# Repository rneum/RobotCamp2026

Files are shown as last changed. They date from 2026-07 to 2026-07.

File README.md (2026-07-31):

PLEASE FILL OUT THE SURVEY HERE: https://utexas.qualtrics.com/jfe/form/SV_4Vpkfo9J5wA6hvg

This repository will hold the lab guides and code for the Robotics Summer Camp at The University of Texas at Austin for Summer 2026.
This camp will be based around the Longhorn Hapkit 1-DOF.
New files will be uploaded as the camp progresses so stay tuned!

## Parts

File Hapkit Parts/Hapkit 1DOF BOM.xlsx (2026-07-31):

Part | Qty per kit | Link
Motor | 1 | https://www.pololu.com/product/4860
Motor Driver L298N | 1 | https://www.amazon.com/dp/B0C5JCF5RS/ref=pe_386300_440135490_TE_simp_item
12V 2A Power Supply | 1 | https://www.amazon.com/dp/B0DFPNZ77T/ref=pe_386300_440135490_TE_simp_item?th=1
Barrel Jack adaptor | 1 | https://www.amazon.com/dp/B079RCNNCK/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
Arduino Uno | 1 | https://www.amazon.com/dp/B0B6VV7MS7?qty=65&sbo=RZvfv%2F%2FHxDF%2BO5021pAnSA%3D%3D
Jumper Wires M-M 10cm | 8 | https://www.amazon.com/dp/B0BRTL3BHR/ref=pe_386300_440135490_TE_simp_item?th=1
Jumper Wires M-M 20cm | 1 | https://www.amazon.com/gp/product/B0BRTJQZRD/ref=sw_img_1?th=1&qty=2
Jumper Wires F-M 20cm | 3 | https://www.amazon.com/California-JOS-Breadboard-Optional-Multicolored/dp/B0BRTHR2RL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
Ball bearing 608 | 2 | https://www.amazon.com/dp/B09PKD8QZZ/ref=pe_386300_440135490_TE_simp_item?th=1&qty=7
Philips #1 Screwdriver | 1 | https://www.amazon.com/Wiha-96110-Phillips-Screwdriver-Precision/dp/B0006OBFP4
4mm allen wrench | 1 | https://www.amazon.com/dp/B0D984S6SD/ref=pe_386300_440135490_TE_simp_item?th=1
Eyeglass screwdriver philips | 1 | https://www.amazon.com/TorSor-Eyeglass-Screwdriver-Keychain-Eyeglasses/dp/B0CM8SWMXC?s=hi&qty=6
Storage bin | 1 | https://www.amazon.com/dp/B01MR7L1VD?qty=6&sbo=RZvfv%2F%2FHxDF%2BO5021pAnSA%3D%3D
M6 shoulder bolts | 1 | https://www.mcmaster.com/92981A202/
M6x1 Nut | 1 | https://www.mcmaster.com/90591A151/
M3x0.5 10mm flat head screw | 9 | https://www.mcmaster.com/92010A120/
M3x0.5 Nut | 9 | https://www.mcmaster.com/91828A211/
M5x0.8 30mm socket screw | 1 | https://www.mcmaster.com/91290A194/
M5x0.8 nut | 1 | https://www.mcmaster.com/90591A260/
4-40 3/8" pan head screw | 2 | https://www.mcmaster.com/91735A104/
Compression fitting | 2 | https://www.mcmaster.com/3898T29/
Wire rope | 16" | https://www.mcmaster.com/8930T16-8930T543/
Wire rope (extra in case of breaks) |  | https://www.mcmaster.com/8930T16-8930T542/

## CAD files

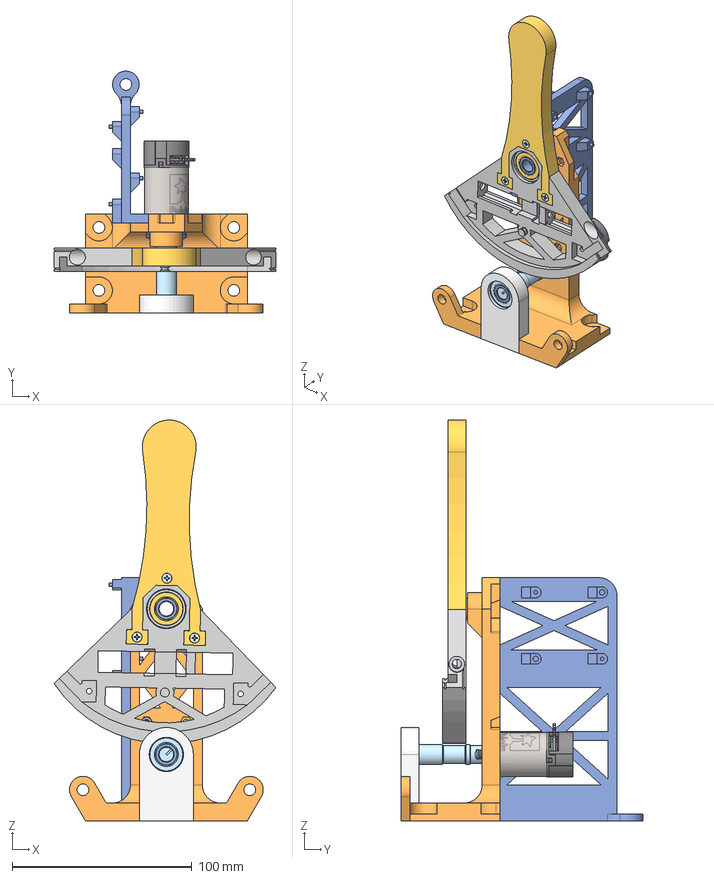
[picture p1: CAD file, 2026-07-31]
Hapkit Parts/1DOF STL/1-DOF Assembly.step
123.3 x 134.4 x 223.0 mm
PCB Mount
91828A211_Corrosion-Resistant 18-8 Stainless Steel Hex Nut x 5
25d-gearmotor-1-no-gearbox-encoder x 2
6153K71_Stainless Steel Ball Bearing x 32
91735A104_316 Stainless Steel Pan Head Phillips Screw x 4
Spacer x 2
Bearing Housing
Base for vert print
Motor Shaft
Handle
92010A120_Passivated 18-8 Stainless Steel Phillips Flat Head Screw x 5
Tensioner
Sector Pulley

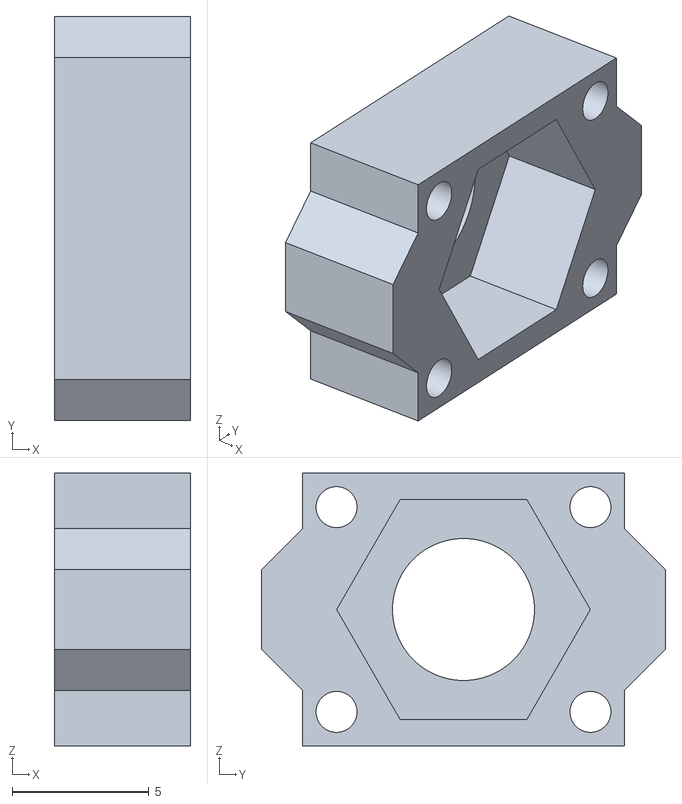
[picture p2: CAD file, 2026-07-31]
Hapkit Parts/1DOF STL/Tensioner.stl
5.00 x 14.8 x 10.0

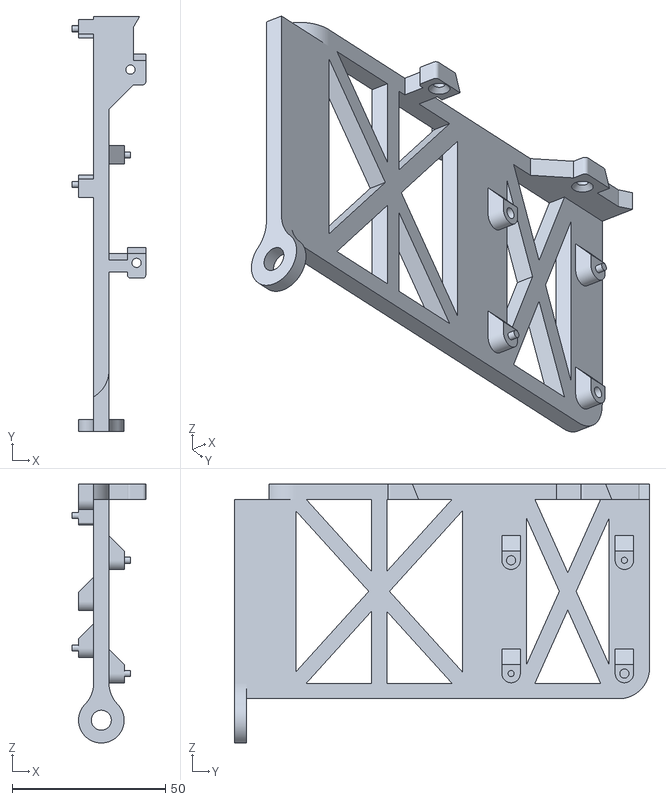
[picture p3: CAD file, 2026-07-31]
Hapkit Parts/1DOF STL/PCB Mount.stl
24.0 x 135.3 x 84.4

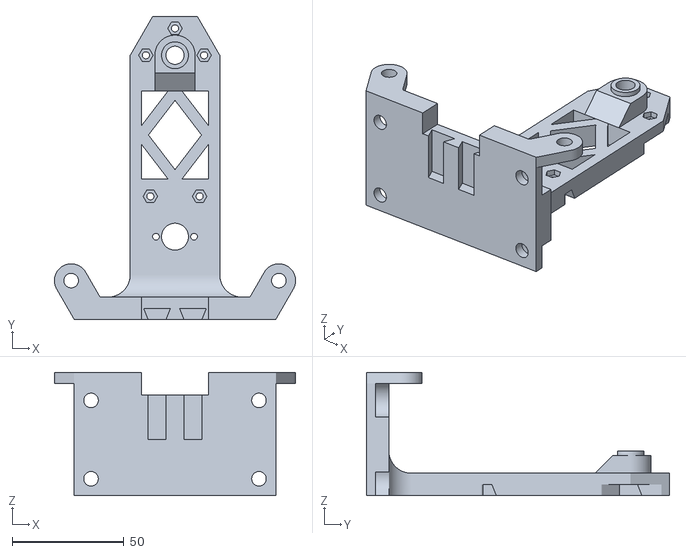
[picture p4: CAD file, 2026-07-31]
Hapkit Parts/1DOF STL/Base.stl
107.7 x 135.3 x 55.0

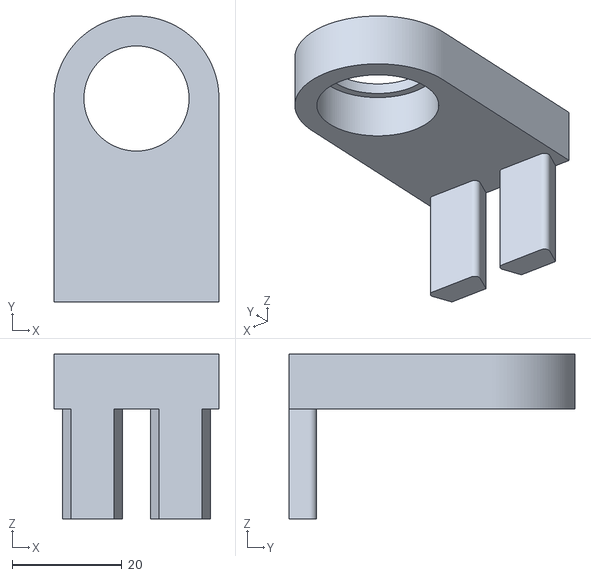
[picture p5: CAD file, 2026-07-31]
Hapkit Parts/1DOF STL/Bearing Housing.stl
30.0 x 52.0 x 30.0

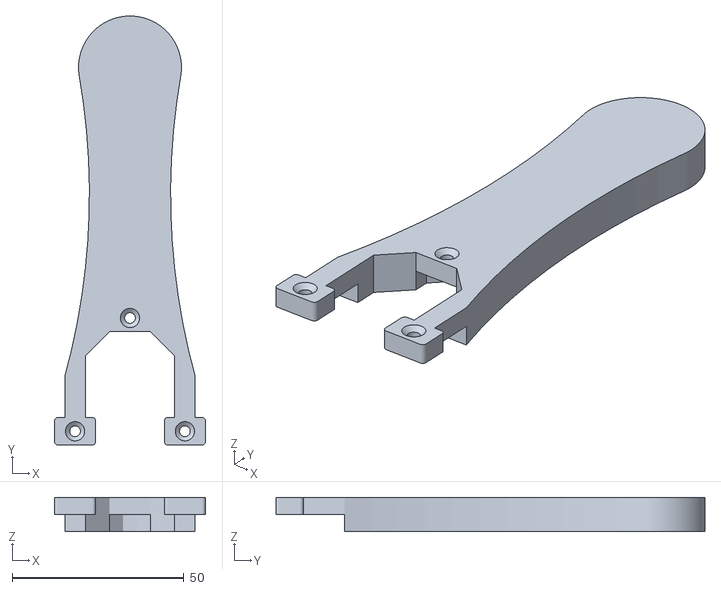
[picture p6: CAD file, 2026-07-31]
Hapkit Parts/1DOF STL/Handle.stl
44.0 x 125.0 x 10.0

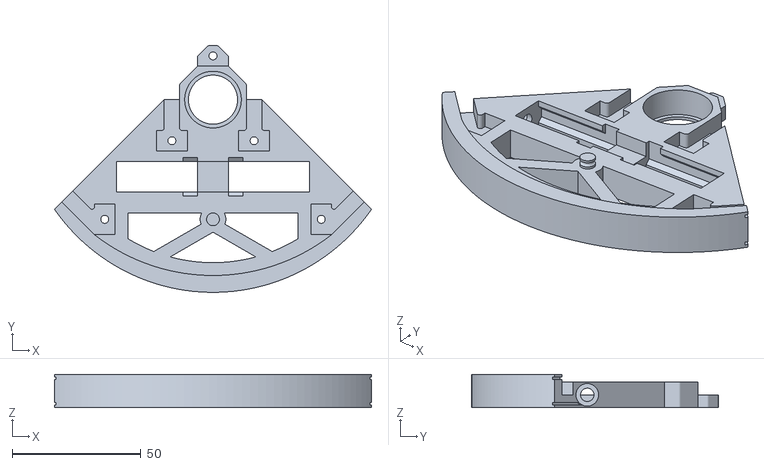
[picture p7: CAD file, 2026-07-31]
Hapkit Parts/1DOF STL/Sector.stl
123.4 x 96.0 x 13.0

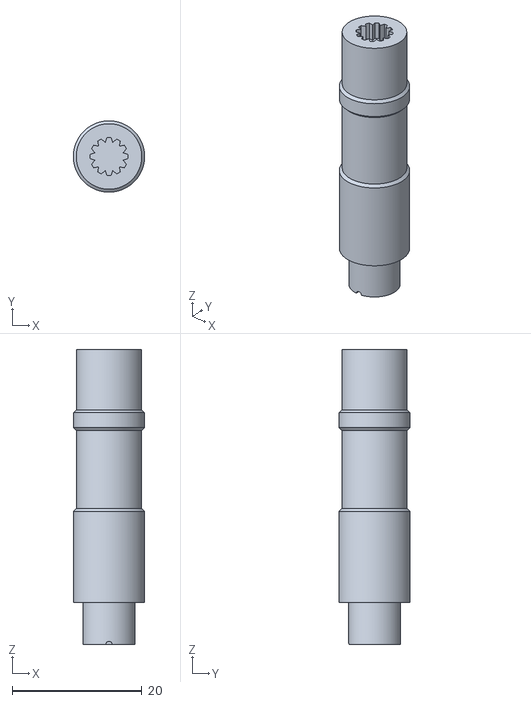
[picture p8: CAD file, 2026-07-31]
Hapkit Parts/1DOF STL/Motor Shaft.stl
11.0 x 11.0 x 45.5

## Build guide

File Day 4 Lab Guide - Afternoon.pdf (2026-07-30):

ROSS NEUMAN
Assistant Professor of Practice, The University of Texas at Austin

SUMMER 2026

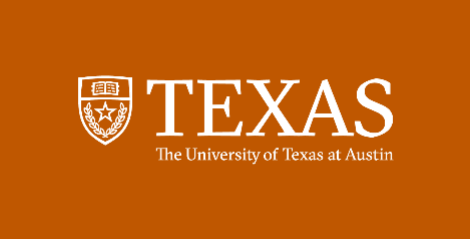
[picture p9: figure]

## LONGHORN HAPKIT

Lab guide #4 - afternoon

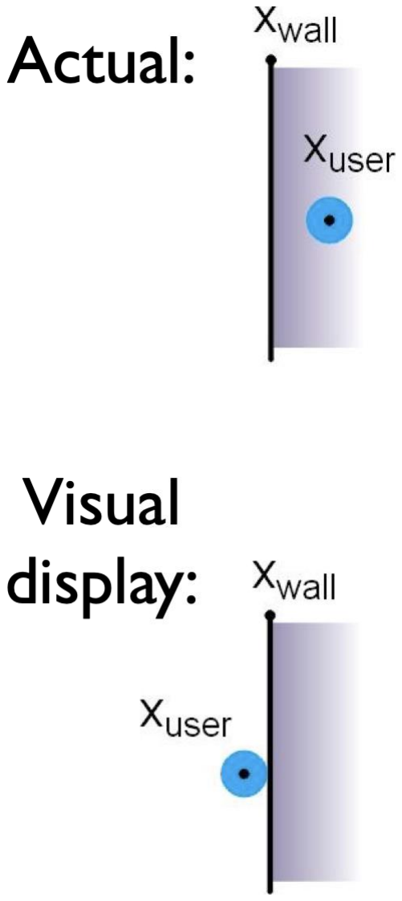
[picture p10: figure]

One more way to make a wall better: Visual Feedback of Stiffness
- trick: never show the point
passing into the surface, even if it is!
- psychophysical studies have shown that this makes the
surface appear stiffer to the user

Scripts are uploaded to show all environments we have discussed

- all_environments contains, well, all the environments we’ve talked about
- Let me know if you have questions about any of them

Making your PWM fast and silent

- all_environments_fast_PWM has the same environments, but with PWM at 20,000 Hz instead of 490

How did it become quiet?

- Default Arduino PWM frequency on pin 6 is 980Hz – This is basically a B5 for music people
– VERY audible
- Humans typically hear from about 20-20,000Hz
- ATmega328 chip (arduino’s brain) is capable of higher PWM – Need to talk directly with the timers
– Timer is a hardware counter that increments at a known rate derived from CPU clock
– CPU clock on arduino is 16MHz (16,000,000 cycles/second)

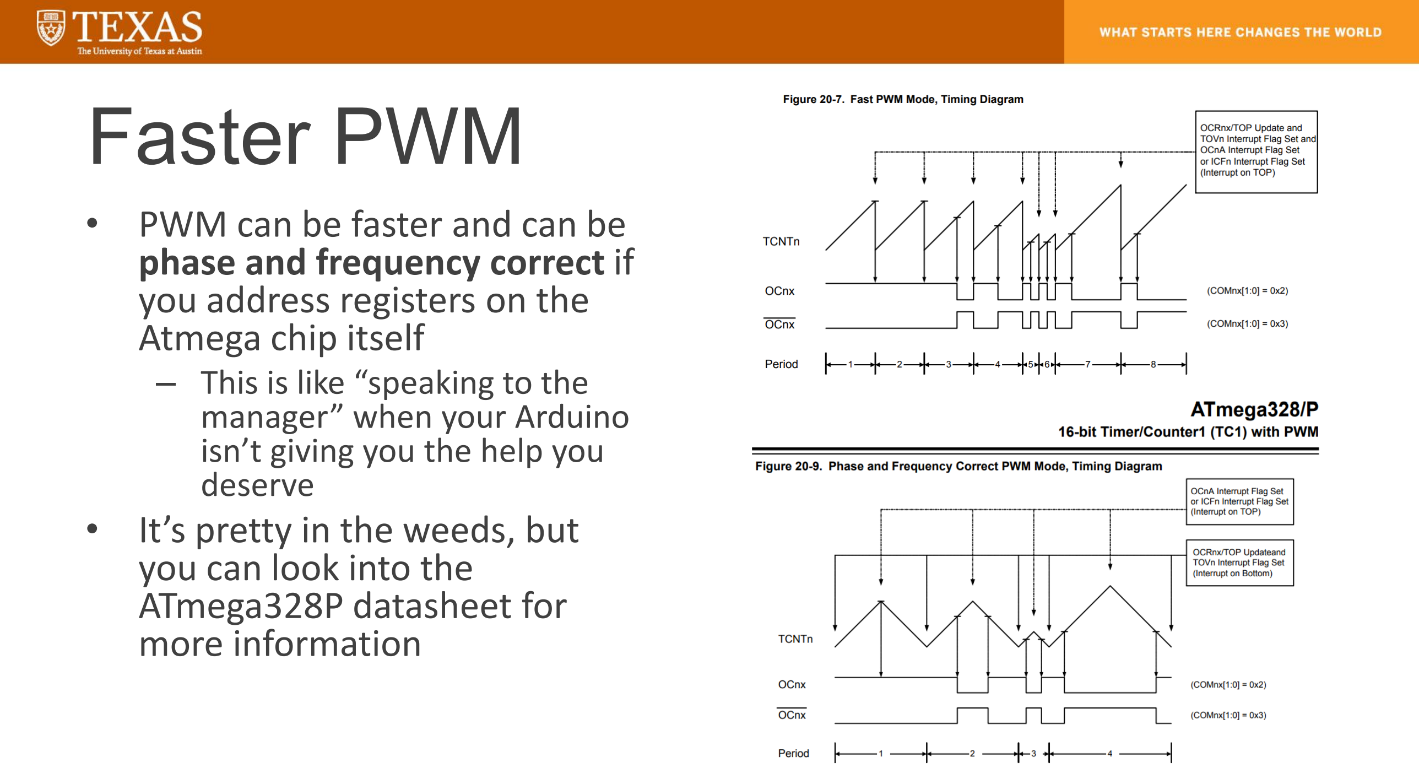
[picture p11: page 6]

Faster PWM

- PWM can be faster and can be phase and frequency correct if you address registers on the Atmega chip itself
– This is like “speaking to the manager” when your Arduino isn’t giving you the help you deserve
- It’s pretty in the weeds, but you can look into the
ATmega328P datasheet for
more information

Talking to the chip

- Rather than using built-in arduino commands, we are talking straight to the MCU onboard
- This mostly consists of setting registers

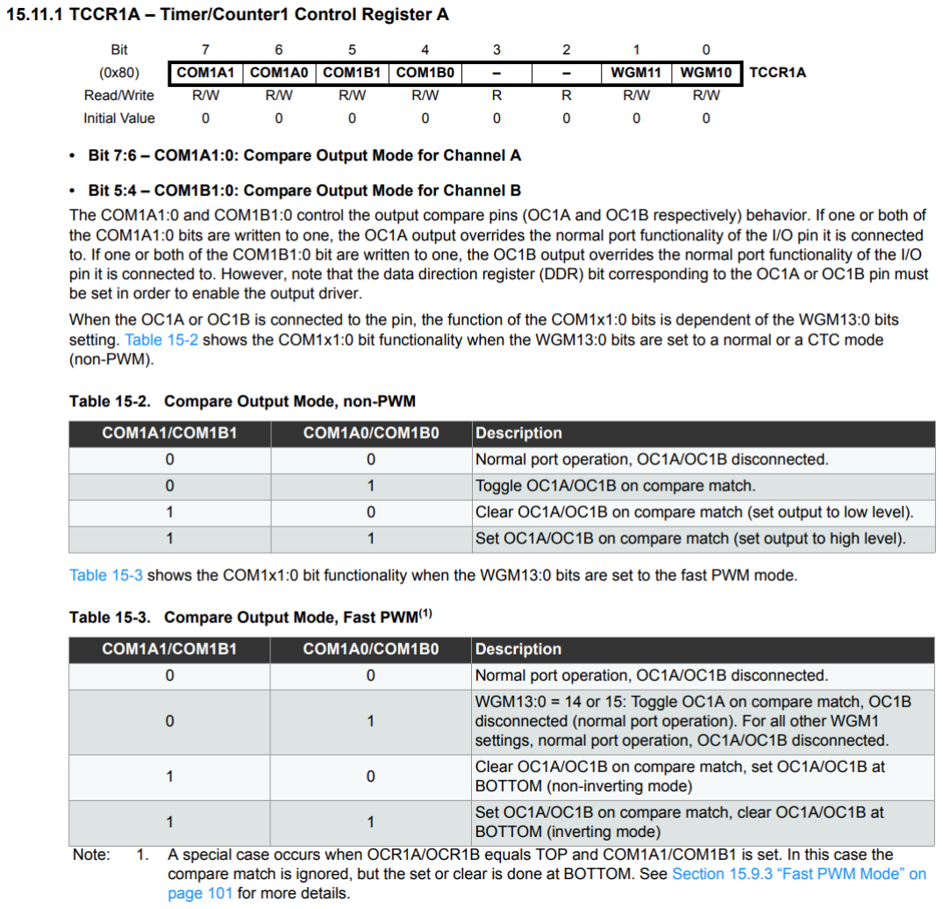
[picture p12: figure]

Registers

- Registers in this case are basically 8 bit numbers that tell the MCU different modes to operate in
- We are setting Timer/Counter1 Control Register A or TCCR1A to
- When we type
- TCCR1A = (1 << COM1A1);
- We are setting the value of TCCR1A to 10000000
- This sets non-inverting PWM

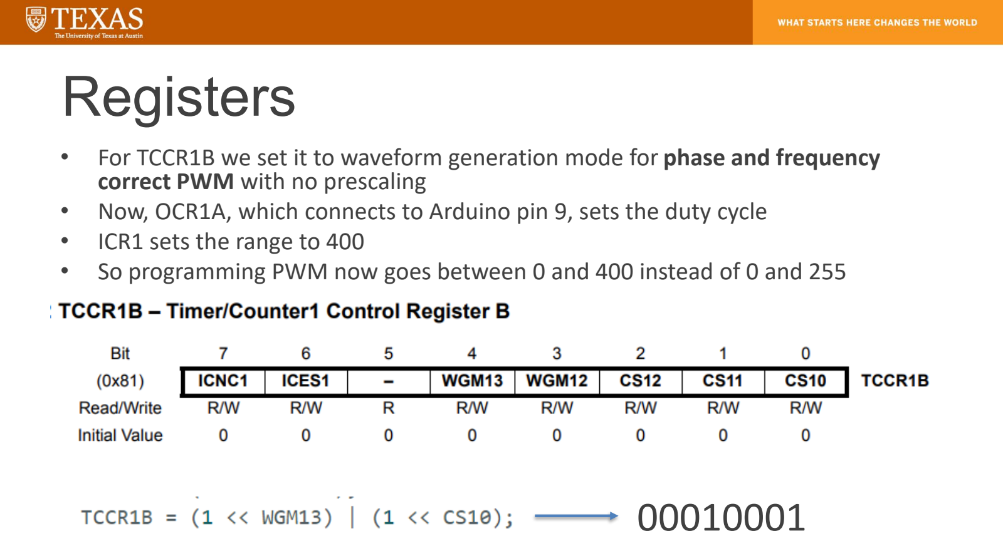
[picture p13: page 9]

Registers

- For TCCR1B we set it to waveform generation mode for phase and frequency correct PWM with no prescaling
- Now, OCR1A, which connects to Arduino pin 9, sets the duty cycle
- ICR1 sets the range to 400
- So programming PWM now goes between 0 and 400 instead of 0 and 255

00010001

Bot’n’Roll

- We have “botnroll one A” kits if you are tired of the hapkit
- Use in groups or pairs, not enough for everyone
- I have never used them, you’re on your own
- https://botnroll.com/onea_en/

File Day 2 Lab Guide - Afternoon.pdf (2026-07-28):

ROSS NEUMAN
Assistant Professor of Practice, The University of Texas at Austin

SUMMER 2026


## LONGHORN HAPKIT

Lab guide #2 - afternoon

After springs, bumps, and walls
- So far all of our commanded forces have been related to the position of the end-effector (handle)
- Sometimes we want to instead have them relate to the velocity of the handle

velocity =

position
time

How do we get the time?

- Currently our superloop simply runs as fast as it can
- This means we don’t have a good measure of how much time elapses between runs
- Solution: we make another loop that does run at a given time

Interrupt Service Routine (ISR)

- ISR uses a timer onboard the microcontroller and counts for a certain number of clock cycles
- Once it hits the number, it triggers the ISR to run immediately

How are we handling haptic loop now?

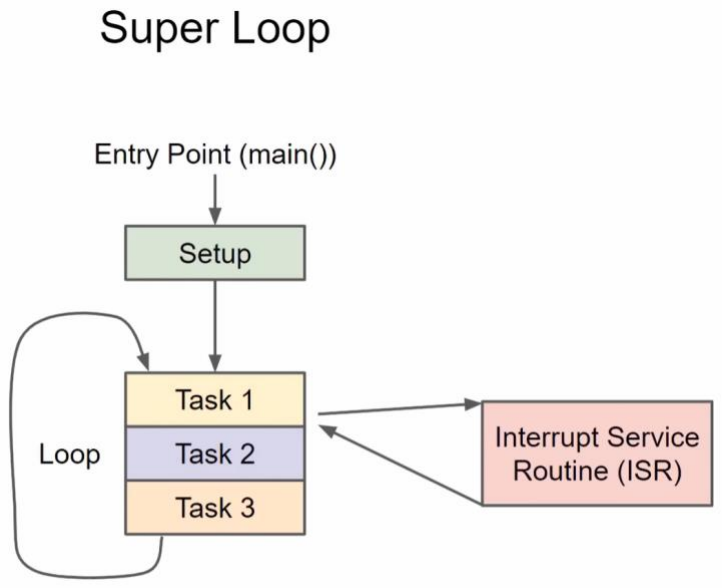
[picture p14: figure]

- Rather than running each loop
task sequentially, ISR initiates at
precise time intervals
– Processor finishes current instruction
– Jumps to ISR
- Only preempted by higher-priority interrupts like…?
- Encoder!
– This is fine because encoder is super fast

Haptic loop handling – ISR setup

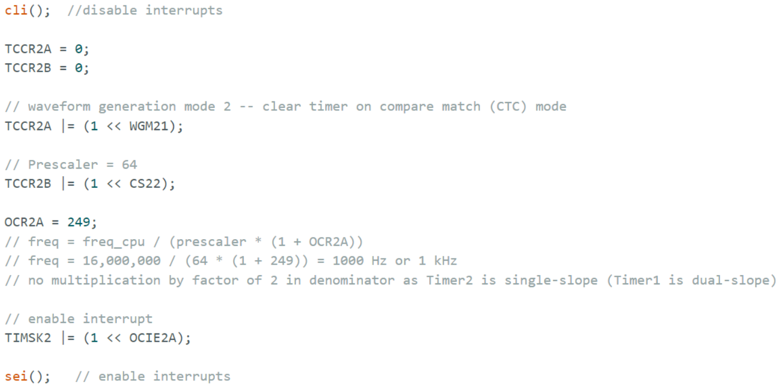
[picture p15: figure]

Haptic Loop Handling - ISR

- ISR is a separate loop from
the “superloop”
- Use this for computation of
quantities necessary to haptic rendering
- Do not use this for things like printing to serial monitor
– Serial prints are very slow
– This is what the regular loop() function can be used for now

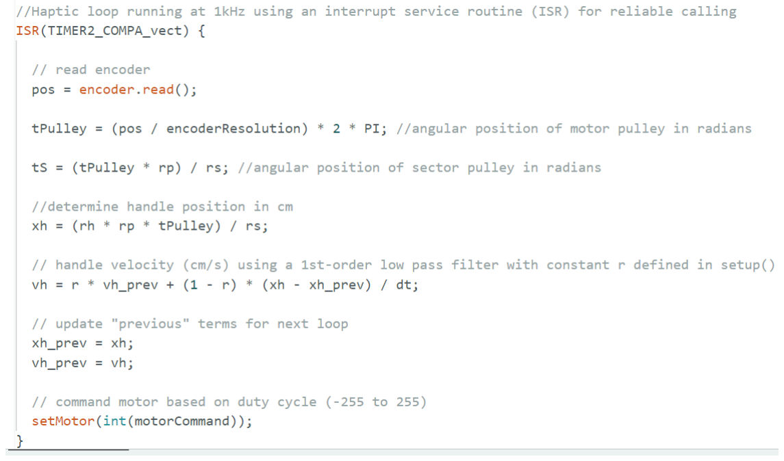
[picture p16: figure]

ISR – The catch

- What happens if an interrupt is triggered before the ISR is finished executing?
- It triggers the ISR inside of the ISR
- System can very quickly go unstable
- This is why one should keep the code within the ISR lean and straightforward
– In our case it needs to execute in 1ms or 16,000 clock cycles
– Serial calls or lots of FLOPs can make this a reality

How the new code flows:

- No need to touch any of the ISR stuff
- Changes you make should occur in elsewhere:
– Haptic modes in loop()
– Serial communications in loop()
– Variable declarations above

Springs and Dampers

- Spring force is a restoring force that tries to pull an object back to equilibrium
– Follows Hooke’s law: Fs = −kx
– k is spring constant
– x is how far string has been stretched
– Only relies on object’s position
- Damping force is a dissipative force that tries to stop motion by pulling energy out of it
– Follow the equation Fd = −bxሶ
– Where b is the damping coefficient (viscosity), and
– xሶ is the velocity of the object (time derivative of position)

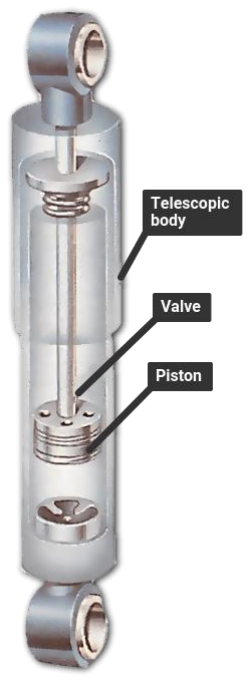
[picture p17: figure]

Springs and Dampers

- Often times real-world
systems/interactions
exhibit both types of
force
- Consider an automotive
suspension

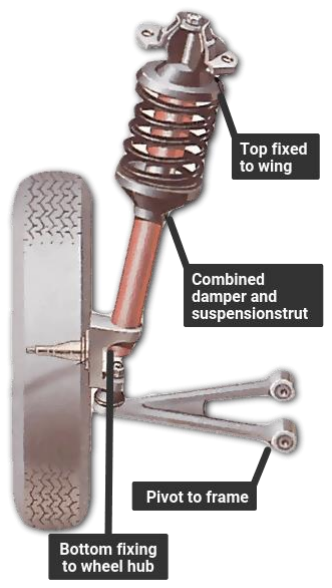
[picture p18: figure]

Underdamped, Overdamped, Critically Damped
- The system dynamics that result are relevant to all sorts of systems
– Mechanical
– Electrical (RC circuits)
– Financial
– Population dynamics

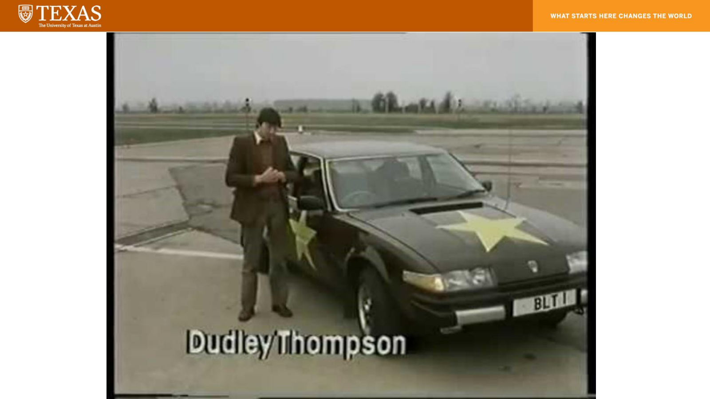
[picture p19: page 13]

Creating damping in haptic devices

- Creating a damper is relatively simple, as you just need a damping term and the velocity: Fd = −bxሶ
- However, determining the velocity requires care

Velocity Estimation

- Need to take a time derivative of positions – We have positions (encoder)
– We have idea of time (haptic loop at 1 kHz)
- However, differentiation of encoder positions creates/amplifies noise
- Filtering is required to get smooth, usable values of velocity
– Filtering introduces delays, reducing transparency
– Must find a good balance

Method 1: Raw Differentiation

- vk =

dx
dt

= xሶ =

(xk−xk−1)
dt
– xk is current handle position
– xk−1is position of handle at the last time step
– dt is the time step
- Our haptic loop is 1 kHz, meaning dt is .001s or 1ms
- This approach is very noisy and pretty much unusable for force feedback devices
- Let’s code it out

Method 2: Windowed Velocity

- vk =

dx
dt

= xሶ =

(xk−xk−N)
N∗dt
- Creates a “moving window” that averages out over N samples
- Pros:
– In this approach you have much lower noise
– Predictable and reliable
- Cons:
– Introduces delay of ~window size/2
– Larger windows make “softer” haptic response – Windows above 10ms are too mushy

Method 3: Low-Pass Differentiator

- vk =

rvk−1+(1−r)(xk−xk−1)
dt
– Where r = e

−2∗pi∗fc∗dt
- Where fc
is the desired cutoff
frequency
- Pros:
– Good balance between noise and delay – Can tune easily by adjusting fc
- Cons:
– Sometimes still harsh or unstable
- Try to implement this in your code!
– Let’s talk about the pseudocode
– Can just use 0.95 for “r” for now
– Try fc values anywhere from 1-60hz or

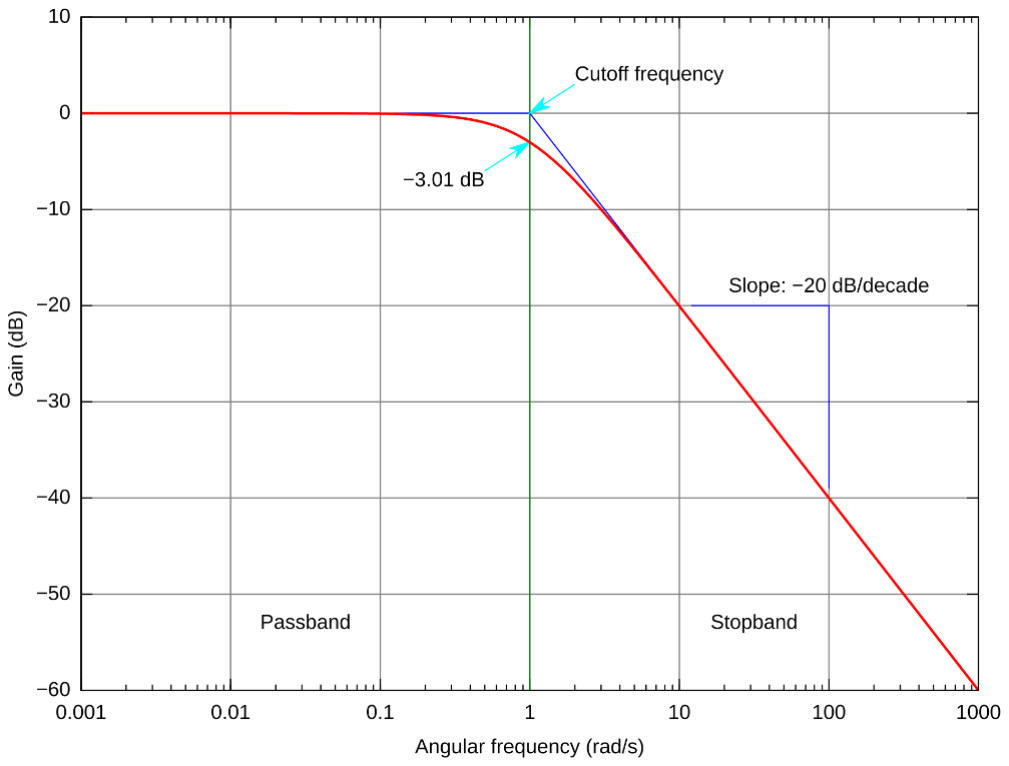
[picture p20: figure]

so and see what works best! | Example low pass filter

Velocity filtering

- This is why we need to filter our velocity
- The code provided implements a 1

st
-order,
discrete time low-pass filter:

Where

Velocity filtering

- When tuning your velocity filter, try changing the value of fc in the loop– this is your cutoff frequency
- The higher your cutoff
frequency, the more high
frequencies will be “passed” through

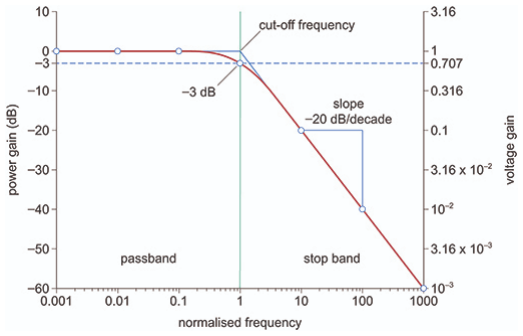
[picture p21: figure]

Damper
- Create a damper
and mess with fc as
well as b to find
what kinds of forces
you can render now
- Damper is included
in the newly
uploaded code

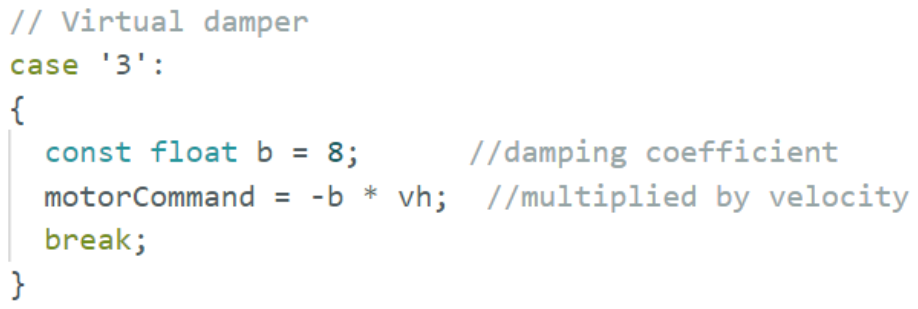
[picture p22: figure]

Spring+Damper

- Add together the effects of a spring and a damper to make a new mode
- See if you can make it go unstable
– If you do make things go unstable, careful not to burn your motor up! Unplug before it’s too late!

Texture

- Alternate sections of

damping and no damping
to create a textured illusion – Can do this with
conditionals
– Can do it with modulus
– Can do using a sinusoid— changing period lets you
change “coarseness” of
texture

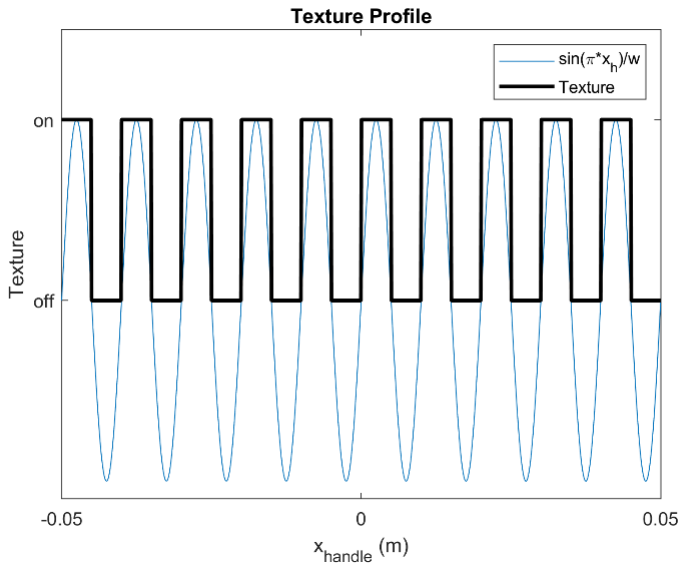
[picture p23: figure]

Add damping to a wall

- Sometimes this helps reject instabilities with high stiffness walls

Continue Developing Virtual Environments

- If you are through with everything, get creative and mix and match these ideas, or come up with your own
- It’s possible to even do simple dynamic simulations

If you are tired of making virtual environments
- Try out Processing
- https://processing.org/tutorials/
- See if you can use it to create real-time graphics related to the Hapkit

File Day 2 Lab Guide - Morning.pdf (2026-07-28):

ROSS NEUMAN
Assistant Professor of Practice, The University of Texas at Austin


SUMMER 2026

# LONGHORN HAPKIT

Lab guide #2 - morning

# https://github.com/rneum/RobotCamp2026

# Kinematics for handle

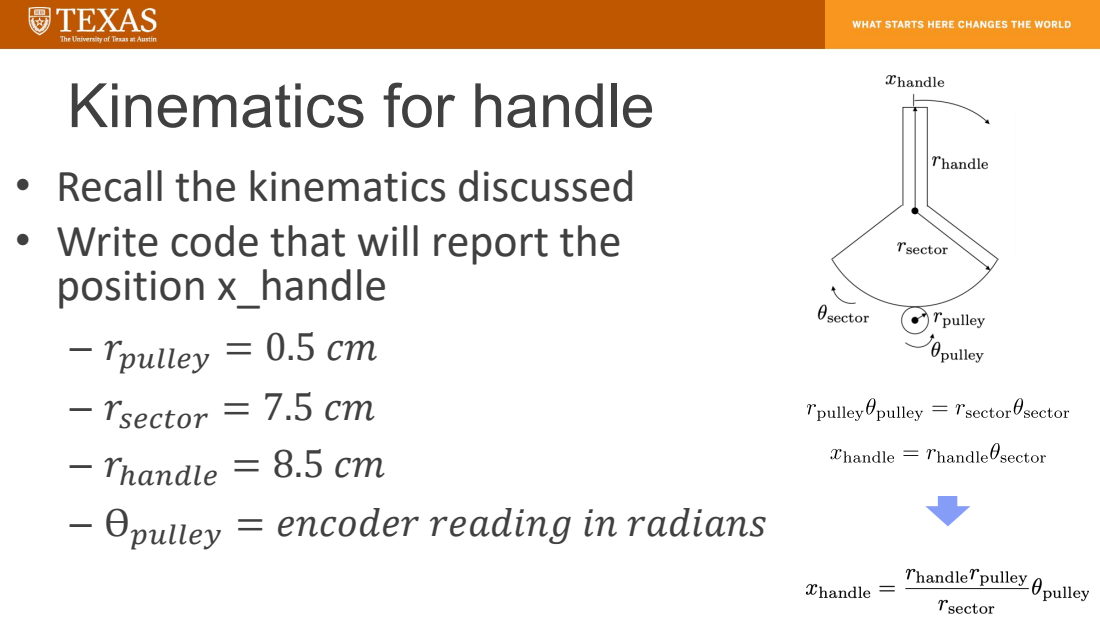
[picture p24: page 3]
– rpulley = 0.5 cm; – rsector = 7.5 cm

• Recall the kinematics discussed
• Write code that will report the
position x_handle

– rℎandle = 8.5 cm
– ϴpulley = encoder reading in radians

# Kinematics for handle

# - Code should look something like this - xh is the position of the handle in cm

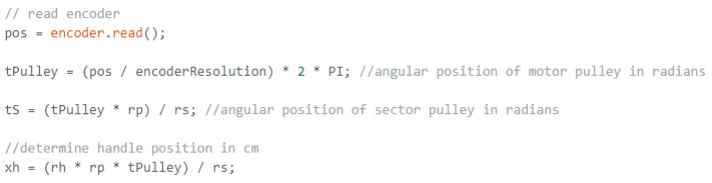
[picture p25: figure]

# Now we will use this position to inform:

# - A virtual spring - A virtual wall

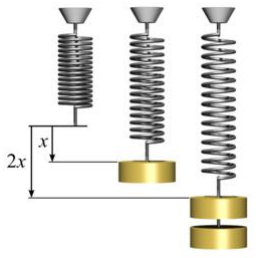
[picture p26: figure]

# Virtual Spring

- Fspring = −k ∗ xℎandle

### - This is also known as “Hooke’s Law” - “k” is your spring constant, or stiffness - You should play around with different values of k to see what the limits of your hapkit feel like - F_spring, for our purposes, will just be the command sent to the motor

– This is because we are equating our voltage command to the motor with the amount of force produced
– This is not correct, but works okay for this situation

# Create a Virtual Wall

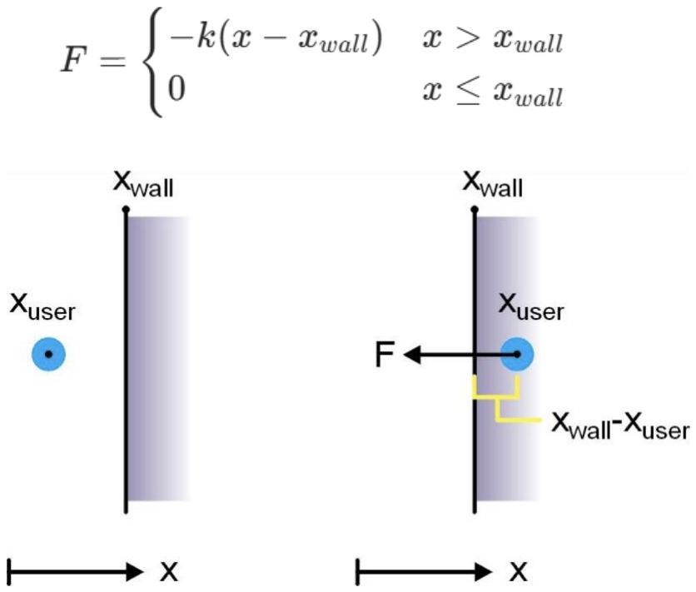
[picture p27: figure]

# - Decide on a location for your wall - Write a conditional statement (if/else) that will command a very high stiffness once you are “inside” the wall

# With your virtual wall

# - Try moving the wall around

# – Place at +3cm – Place at -2cm – Place two virtual walls simulateously

# Use serial to send commands

- Serial can also be used to send commands,
not just read out what the program is
offering
- Serial.read() tells the serial monitor to read commands the user is entering when available
- Set serial monitor to “no line ending”
- Create a new variable called “mode” that you will use to tell the program which haptic environment to render
– Put this at the top where you are declaring other variables like pos, xh, etc.
- Now in loop() you can read for the mode
- Continued on next page…

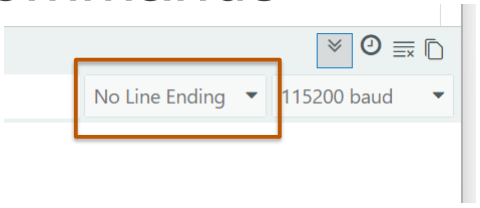
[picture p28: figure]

## With variable declarations:

## In loop():

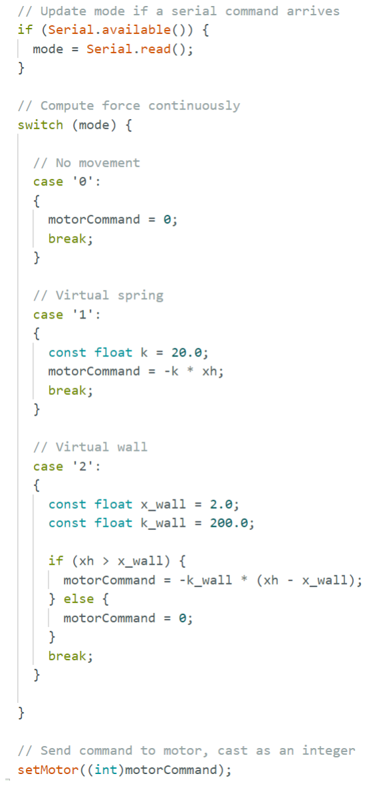
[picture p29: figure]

# Commanding Modes

## - The code shown to the side implements a switch statement that allows you to switch between your spring and wall mode without re-uploading the code - You can add more cases to this statement as you develop more virtual environments if you like this workflow better

# Make a zeroing function

## - Another convenient function is to have one that resets the encoder

to 0

## – If your capstan slips at all, use this to re-establish your x = 0 point

## - Simply use encoder.write() to tell it the position is now 0

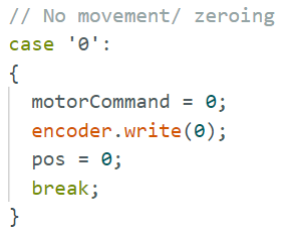
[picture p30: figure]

## - I like to make this my “0” function in the switch statement

# Make a simple “bump”

## - Place a “bump” at a desired location

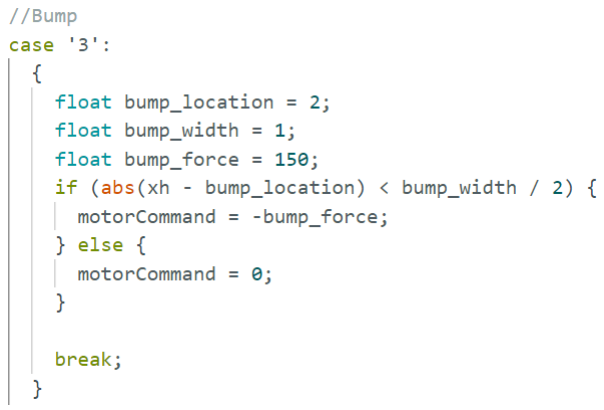
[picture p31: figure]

## - Play around with the

parameters (width,

## force, location) - Try creating multiple bumps - See if you can design a way to make this bump feel more realistic

# More realistic bump

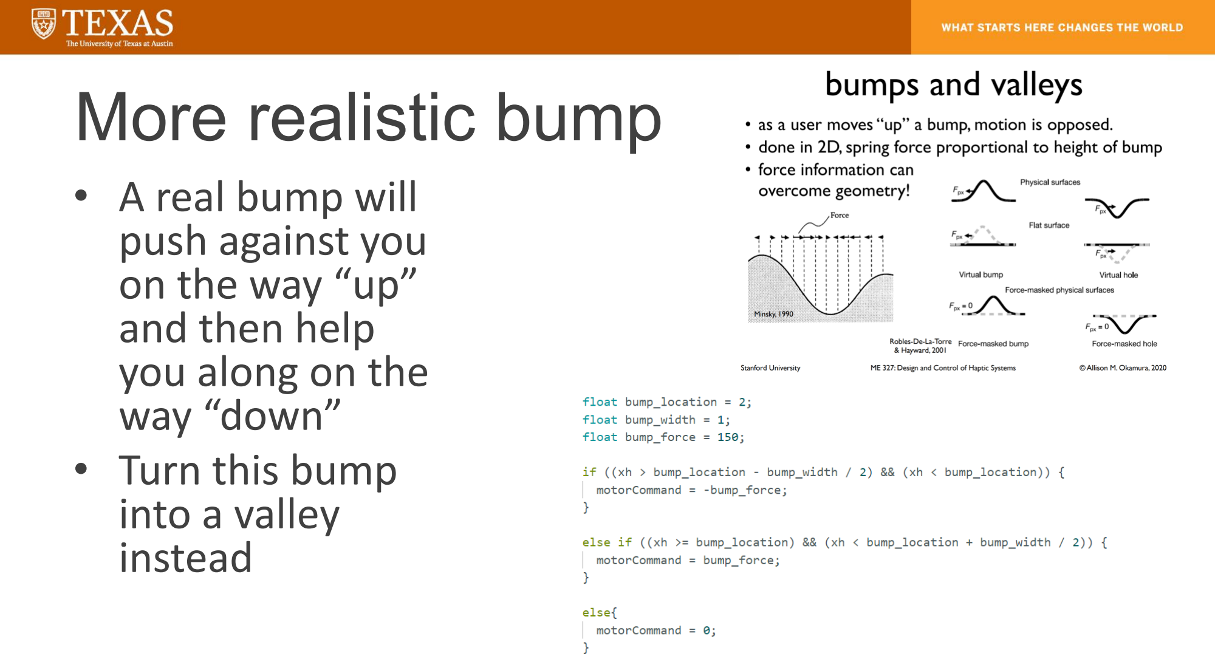
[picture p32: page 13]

# - A real bump will push against you on the way “up” and then help you along on the way “down” - Turn this bump into a valley instead

# Bump and Valley – Continued Improvement

# - For an extra challenge--can you make it feel like a smooth hill instead?

# – Could use sinusoids – Could use piecewise functions

# Continue to experiment with Composing virtual environments

# - Get creative, see what you can make!

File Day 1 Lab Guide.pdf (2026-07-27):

ROSS NEUMAN
Assistant Professor of Practice, The University of Texas at Austin

SUMMER 2026

# LONGHORN HAPKIT

Lab guide #1

# Get a box

## - Feel free to trade around for different colors

## – Colors are all random – All prints with same material

## - Some prints may have support material hanging off, feel free to remove - If you suspect you have a defective part let me know - Label your box (sharpies will be passed around)

# Practices for Part 1 of Camp

- I am only including screenshots of code
– I want you to have practice entering lines of code, this will help you retain what you use
– I will upload the code we discuss today after we are through so you can reference is as the week progresses
- Please don’t use LLMs (ChatGPT, Claude, etc.)
– I want you to use your own brains as we get our robots put together – Later in the week when things are more open-ended, you are welcome to use these tools to bring your ideas to life
- Please do use your neighbors
– Make friends, help each other out, exchange ideas!

# What’s in the Box?

- 3D printed parts
– | Base
– | PCB Mount
– | Sector Pulley
– | Handle
– | Bearing Housing
– | Motor Shaft
- Arduino Uno
- Polulu 12V Motor + Encoder
- L298N Motor Driver
- 12V DC power supply
- Tensioning slider+cable
- 2 Ball bearings
- Bag of hardware
- Screwdriver (Philips #1)
- Tiny Screwdriver
- 4mm Hex Driver (aka Allen wrench)
- Wires
- Bag of Hardware

# Assemble! Mount Motor to Base

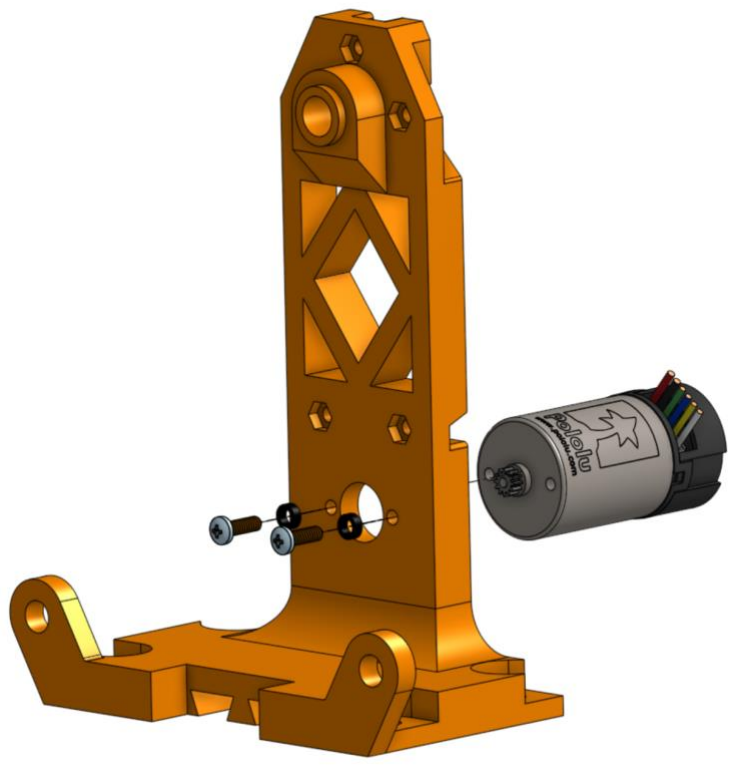
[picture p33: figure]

- Use the 2 round-head
screws along with the 2
spacers and secure the
motor to the base
– It will help later if you do this with the motor
wires oriented upward
- You may need to drive the screws to get them
through the mounting
holes

# Connect the Base and PCB Mount

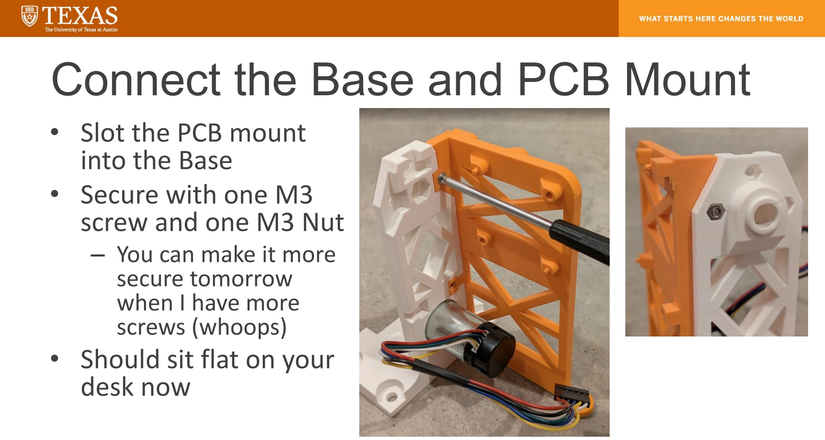
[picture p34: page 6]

### - Slot the PCB mount into the Base - Secure with one M3 screw and one M3 Nut

– You can make it more
secure tomorrow
when I have more
screws (whoops)

### - Should sit flat on your desk now

# Attach Arduino and Driver Board

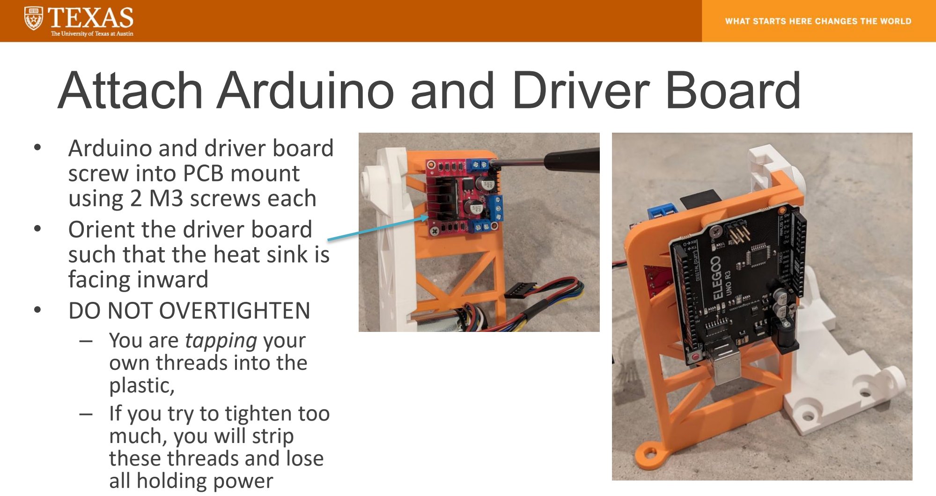
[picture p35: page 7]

- Arduino and driver board screw into PCB mount
using 2 M3 screws each
- Orient the driver board
such that the heat sink is facing inward
- DO NOT OVERTIGHTEN
– You are tapping your
own threads into the
plastic,
– If you try to tighten too much, you will strip
these threads and lose
all holding power

# What is Arduino?

- Arduino is a microcontroller development board that allows easy interfacing with the chip on board
- In industrial applications, PCBs would be designed specifically for the given embedded system, but this allows for
reconfiguring/tinkering/exploring
- Our Arduino Uno is based around the ATmega328P, an 8-bit
microprocessor

# Arduino IDE

## - Open up a terminal on your computer and type “arduino” then press enter - You should see the Arduino IDE open up

### – This is where you will write programs to upload to your Arduino

## - Connect your Arduino to your computer with the included USB cable - Select ttyUSB, search for “UNO” and select Arduino UNO as your board for this port

# Programming Arduino

- Arduino has an IDE that you write
programs in
- Beginner-friendly wrapper on C++
– You can program straight up C++ on the Arduino if you like
- You write a single program (“sketch”) that will run continuously on the board whenever it is powered
– setup() runs once at the beginning
– loop() the runs continuously as long as the device remains powered on
– This is known as a “superloop”

# Blink—The “Hello World” of Arduino

## - Arduino has an onboard LED that you can program - It is a pin named with the constant LED_BUILTIN - In your setup section, initialize it as an output pin:

# Blink—The “Hello World” of Arduino

- Now write your loop
- digitalWrite() lets you set your pin to HIGH or to LOW
– | This is your 1 or 0
– | Electrically, it will set the pin to either +5V or 0V
- To turn LED on, send voltage HIGH command
- To turn LED off, send voltage LOW command
- To wait for a given number of milliseconds, use the “delay” function
- Upload it and watch your LED blink!

# Talking to your Arduino

- Arduino uses serial
communication to share
information with other devices
- Serial sends less data per clock cycle than parallel, but
simplicity of transmission allows much higher clock rates
- “Serial monitor” in Arduino IDE allows you to read
information from the board in real time
– Baud rate up to 115200 in serial monitor

# Speed of Serial -- Baud

- “Symbols per second” or pulses
per second of a transmission
medium
- Émile Baudot invented “Baudot code” for early telegraphy
- Operator would enter one symbol for each “click” of the distributor in a cadence
- The “Baud” was the measure of how quickly these symbols would be entered in
- Name stuck around for ensuing serial communications

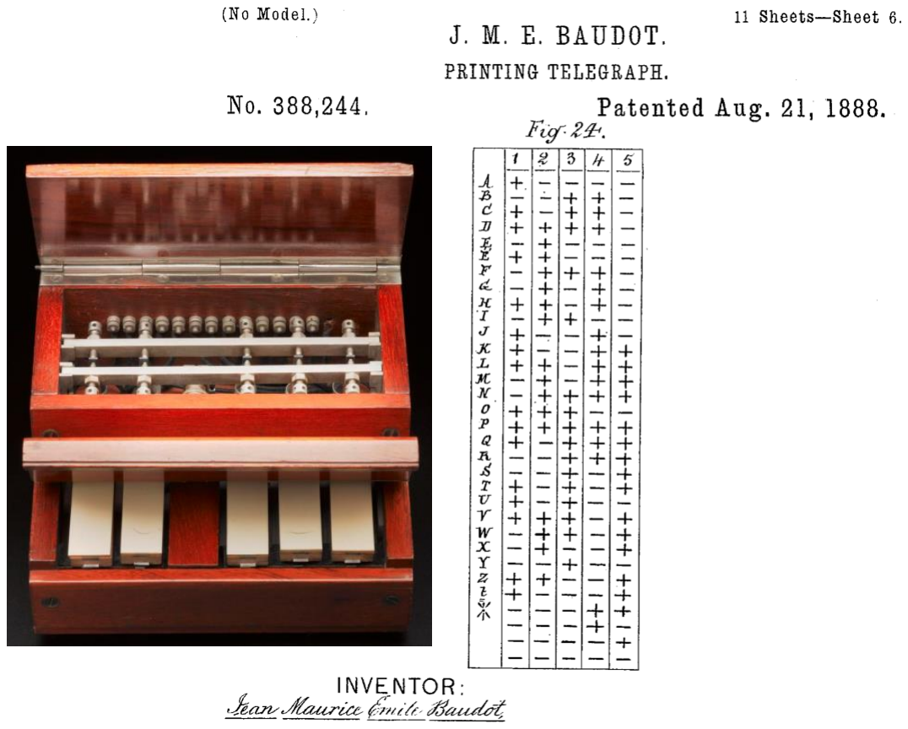
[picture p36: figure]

https://collection.sciencemuseumgroup.org.uk/objects/co33197/baudot-five-key-keyboard-1897-1926

# Adding Serial Communication

- If you want to send messages to the serial monitor in your Arduino IDE, type Serial.begin(desired baud) in the setup portion of your program

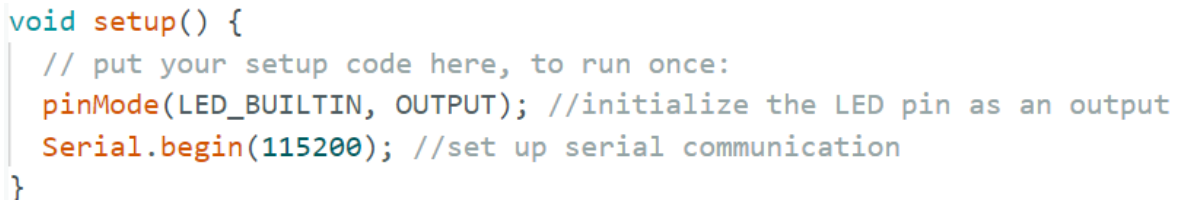
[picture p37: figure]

- To output a message, use Serial.print(“your message”)
- To make each message come up on a new line use Serial.println()

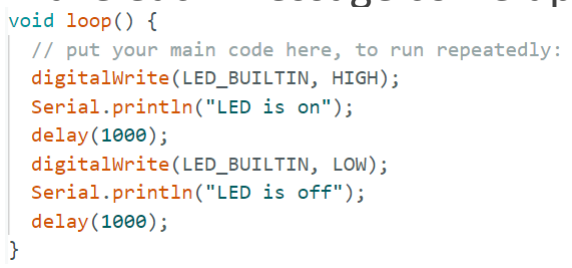
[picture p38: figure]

# Serial Communication

### - To observe the output, open the Serial Monitor with ctrl+shift+M or under “Tools” - Make sure to set the BAUD in the monitor to the same thing you declared in your code

– Might as well set to the fastest at 115200

# Declare a Variable

- Declare an integer variable at the very top of your code
- Increment the variable each loop and report it to serial monitor

# Write a “for” loop

## 1. Start value: int i = 1 2. Condition: I <=5 3. Update: i++

## - Use a loop to blink the light only five times

# Wiring the Motor - Power

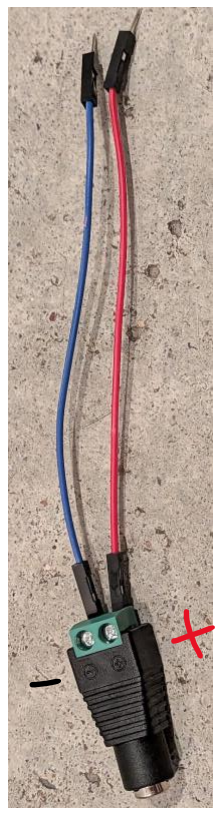
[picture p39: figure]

## - Attach 10cm M-M wires to the positive and negative terminals of the barrel jack - Use your tiny screwdriver to secure in place if your regular one doesn’t reach the screws - Keep track which wire is positive and which is negative

# Motor Driver: L298N

### - “Drives” motor(s) by providing adequate power and switching signals/directions as needed

– Arduino has insufficient power to drive the motor

### - Our 12V power adaptor will connect to this board

# Wiring the Motor - Power

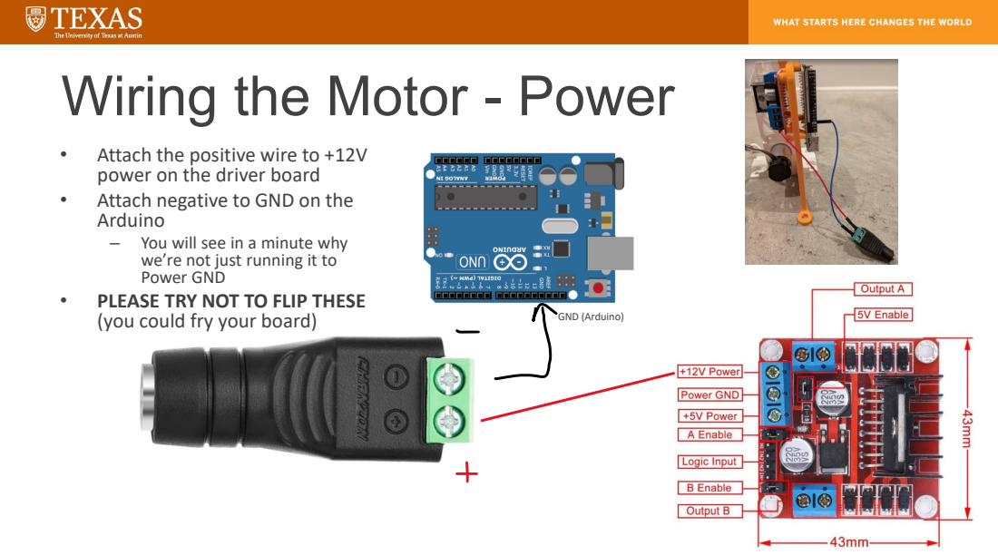
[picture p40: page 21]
You will see in a minute why; (you could fry your board); GND (Arduino)

• Attach the positive wire to +12V
power on the driver board
• Attach negative to GND on the
Arduino
we’re not just running it to
Power GND

• PLEASE TRY NOT TO FLIP THESE

# Motor Driver: Logic

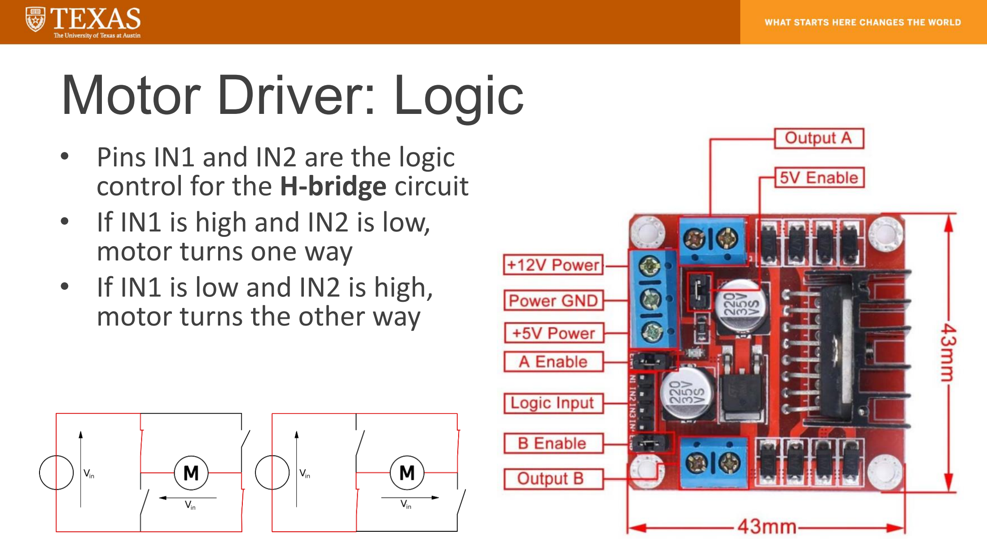
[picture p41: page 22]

- Pins IN1 and IN2 are the logic control for the H-bridge circuit
- If IN1 is high and IN2 is low, motor turns one way
- If IN1 is low and IN2 is high, motor turns the other way

# Wiring the Motor – Logic Inputs

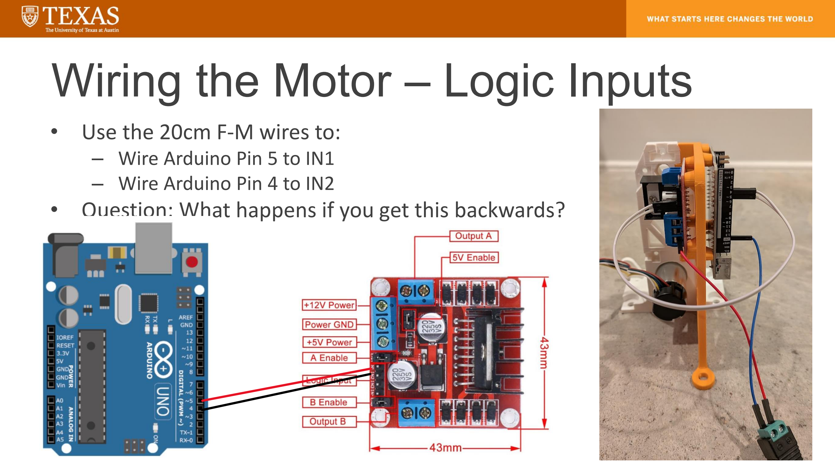
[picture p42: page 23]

- Use the 20cm F-M wires to:
– Wire Arduino Pin 5 to IN1
– Wire Arduino Pin 4 to IN2
- Question: What happens if you get this backwards?

# Wiring the Motor - Outputs

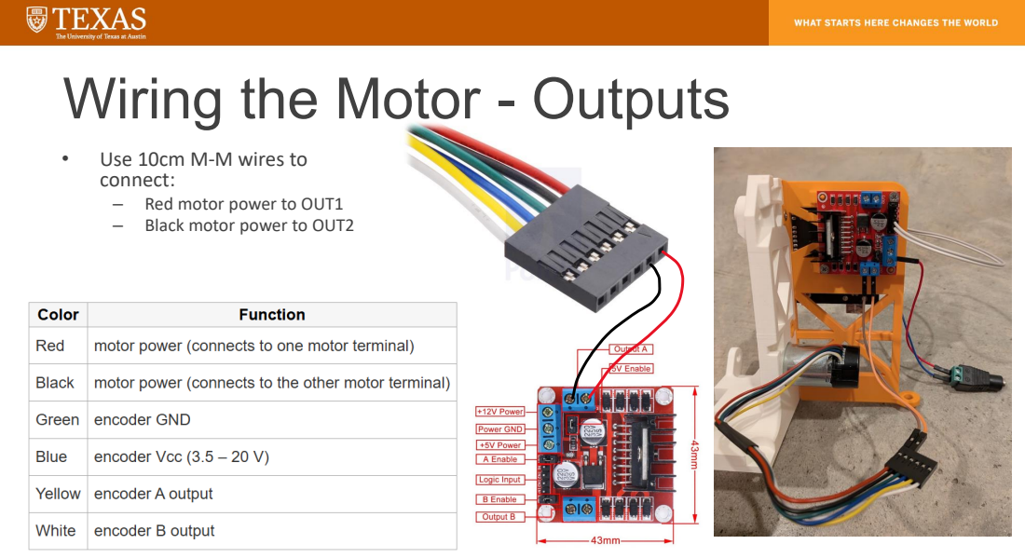
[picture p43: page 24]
Red motor power to OUT1; Black motor power to OUT2

• Use 10cm M-M wires to
connect:

# Wiring the Motor - Grounding

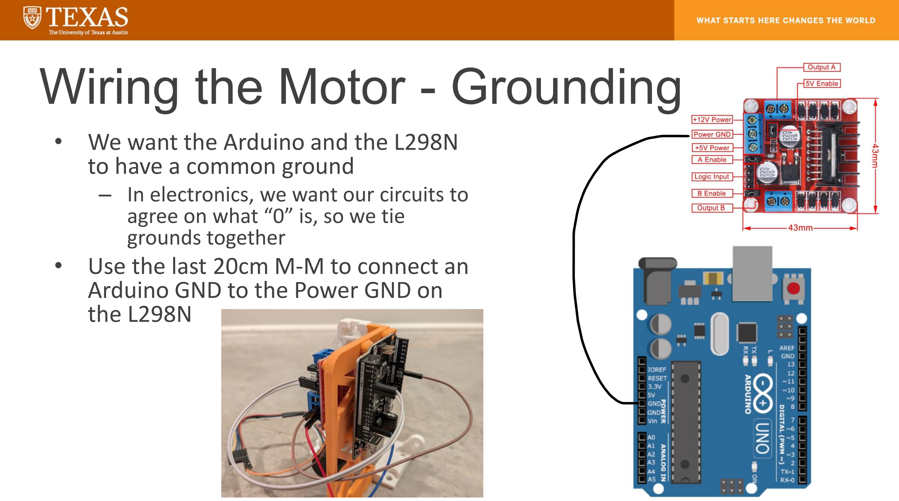
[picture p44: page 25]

- We want the Arduino and the L298N to have a common ground
– In electronics, we want our circuits to agree on what “0” is, so we tie grounds together
- Use the last 20cm M-M to connect an Arduino GND to the Power GND on the L298N

# Attach Motor Shaft

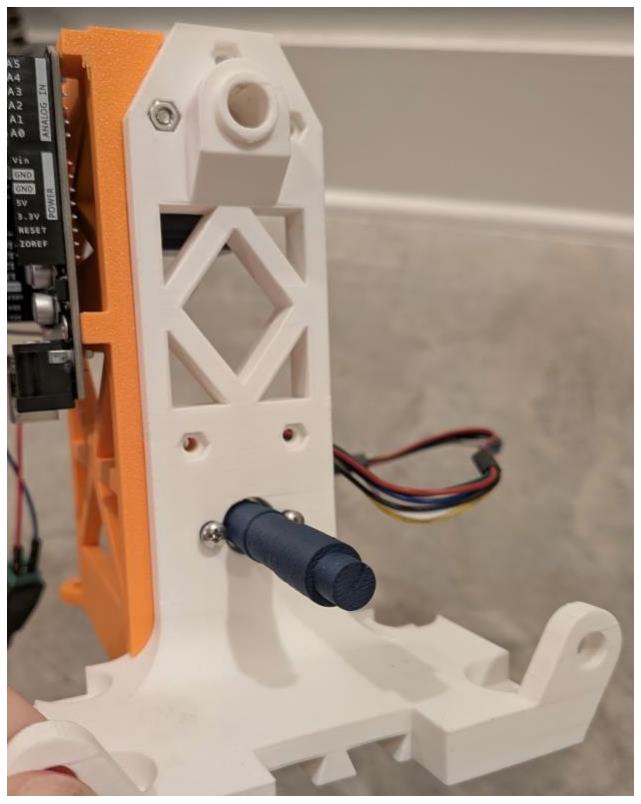
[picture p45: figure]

- This might help you
visualize what the motor is
doing
- Try and get the motor
output gear to mesh with
the gear profile in the
shaft
– You might have to mash
it a bit
– I have extras if yours gets messed up

# Test the Motor

## - At this point, we can run the motor forward or backward – so let’s try it out!

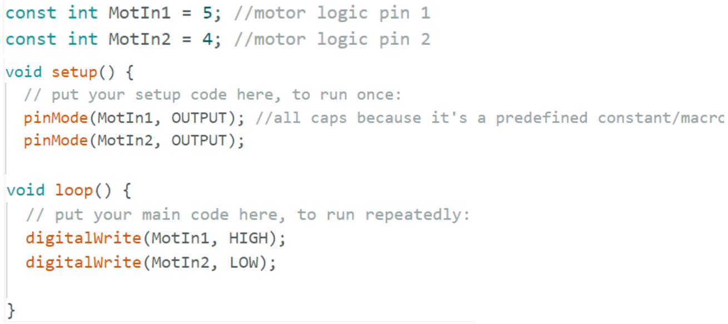
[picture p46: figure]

# How do we change the speed?

## - Speed is roughly proportional to the voltage across the motor’s coils - Before, we were supplying 12V or 0V to the motor - How do we get something in between, when our Arduino output pins just write “on” and “off”?

# Analog vs. Digital Signals

- Analog signals are smooth often
arising from physical phenomena
- Digital signals are discrete
– The more discrete samples in a given window of time, the closer to “analog” you can approximate
- Analog-to-digital conversion is ADC
- Digital-to-analog conversion DAC
- What might these be useful for?
– People spend a LOT of money on good DACs and ADCs
- Do you need a DAC to control a motor?

# The Solution: PWM

- Pulse Width Modulation (PWM) is a way to use digital (on/off) signals to provide “analog” voltages to the motor circuit
- By controlling the proportion of time that the signal is on vs. off, it begins to look like an analog voltage if you switch fast enough

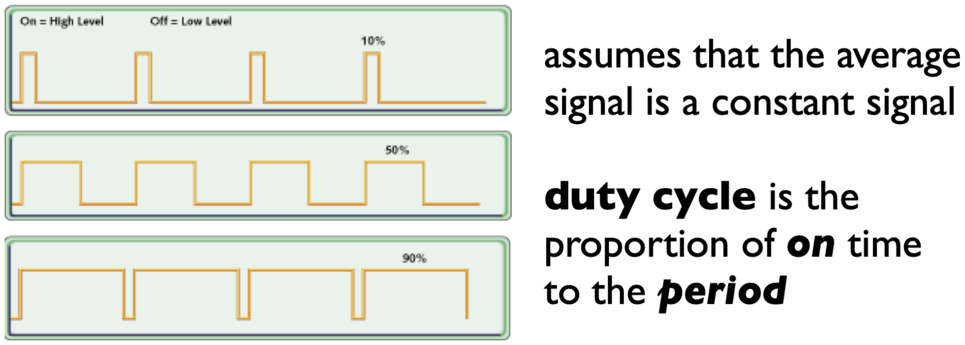
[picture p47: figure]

# Changing Speeds - PWM

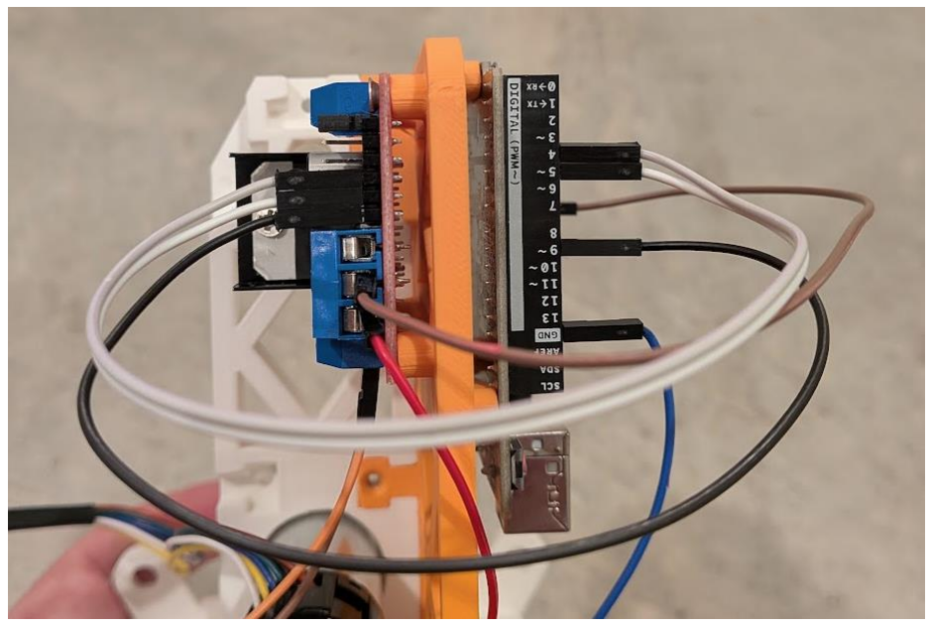
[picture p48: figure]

- Remove the jumper from ENA
– Now we will turn on/off using
PWM from arduino
- Use the last F-M 20cm wire to connect ENA to Arduino pin 9
– Any pin with “~” on Arduino can have PWM output
– Reason for using pin 9 will be discussed later (for now it doesn’t really matter which one you choose)

# Test the PWM

- To use PWM in Arduino, use analogWrite()
- This takes values between 0 and 255 to dictate the duty cycle

# Write a loop to go through speeds

## - Ramp from 0% to 100% duty cycle and back down using for loops

# Write a function to handle motor

# commands

- We want speeds to be positive or negative so the motor can go forward and backward
- Let’s write a function to handle this
- Now you can say, e.g. setMotor(-127) and the function will tell the motor to spin backward at a 50% duty cycle (roughly 6V to the motor)
- Try to modify the ramp function from the previous slide to ramp from negative to positive and back using setMotor() function

# Wiring the Encoder

- Connect encoder ground to a
ground pin on Arduino
- Connect encoder Vcc to 3.3V pin


on the Arduino (5V works fine too) – This powers the encoder from the Arduino
- Connect encoder A and encoder B outputs to pins 2 and 3 on Arduino, respectively
– It doesn’t really matter which digital pins you assign these to, but using this scheme will keep us consistent when sharing code

# Using the Encoder


## - We have a library to handle the quadrature encoder math for us:

### – In Arduino IDE open libraries manager (books icon) – Search “encoder” and install the Encoder library by Paul Stoffregen

# Test it Out


- This script will print the encoder position (in
counts) to the Serial
monitor
- Ln 9: Using the “Encoder” class, we create an instance called “myEncoder” that
passes “encA” and “encB”
as arguments to the class’s constructor
- This is an object
declaration and initiation
- Now you may use the
object to return encoder
counts object by saying
myEncoder.read();

# Using the Encoder

## - Now try to get the encoder to readout in:

## – Degrees – Radians (2π radians = 360 degrees)

# Wiring is complete!


to 12V power supply

to PC

# Assemble the Handle and Sector


- Handle snaps into sector
– Can secure with screws when they arrive…
- Ball bearing press-fits into sector

# Transmissions

## - Why use transmissions?

### – Transmit power from one location to another

- e.g. driveshaft in a car, chain on a bike

### – Trade torque for velocity

- The right transmission ratio will help translate the
motor’s output to the
output needed in a device

# Torque and Gearing

- Which bike would you set a speed record on?
- Which could you actually ride up a hill with?
- We’ll come back to this later

# Cable Transmissions (Pulley-Like)

- Cable transmissions are often
used in haptics and robotics
– Very low friction
– Very low backlash
– Very stiff compared to belt-drive
– These attributes make them highly “transparent”
– Unfortunately they can be a bit of a pain, as you will find out shortly…

# The Capstan

- This is what we will be using
- Has exponentially more
holding force as it has more turns
- Works according to the
equation:

e

μφ =

# Prepare the tensioning mechanism

## - Thread the loop end of the tension slide out of one side of the sector

# Prepare the tensioning mechanism

- Put the M5 nut in the tension slider
- Place the slider into the slot opposite the side of the sector you threaded the loop end through

# Prepare the tensioning mechanism


## - Thread the M5 socket head bolt into the tension slider

# Attach Sector and Handle to the Base


- Use the M6 shoulder screw and M6 nut to secure the
handle/sector to the base
- You can tighten it down, but it is possible to over-tighten. Make sure the handle still spins freely on its bearing

# Configure the Capstan Transmission

## - This is the most difficult part of the whole process - Be patient and accept that you may need to start over a few times - It helps to work with a partner

## – Have partner hold the sector still while you route the cable

# Capstan Cable Routing – Right and Wrong Way


# Capstan Transmission

- Wrap the cable three times around the motor shaft, through the notch on the other side, and secure it to the peg at the center of the sector
– | May need to loosen/tighten the M5 bolt to be able to reach the peg and hold some tension
– | If your cable is too long/short to reach we can get you another one

# Support the motor shaft with the

# bearing housing

- Slide the feet of the bearing
housing into the base to
support the outer end of the motor shaft
- Now you can tighten/tweak the cable until the
transmission and smooth
and has good holding power – Once again, it is possible to over-tighten.
Experimentation will help
find a good balance.

# If you make it to this point, try to:

## - Write a sketch that converts encoder ticks to displacement at the end of the handle

## – Handle distance to axis of rotation: 85mm – Radius of motor shaft: 5mm – Radius of sector: 75mm

## - Program the handle to behave like a spring

## – F_spring = -kx

## - Return the velocity of the handle

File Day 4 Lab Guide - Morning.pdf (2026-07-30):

ROSS NEUMAN
Assistant Professor of Practice, The University of Texas at Austin


SUMMER 2026

# LONGHORN HAPKIT

Lab guide #3

## One more way to make a wall better:


## Visual Feedback of Stiffness

## - trick: never show the point passing into the surface, even if it is! - psychophysical studies have shown that this makes the surface appear stiffer to the user

# Python!

- Let’s use Python to interact with the hapkit
- Open a new terminal tab or window (the one running arduino needs to keep running arduino, don’t mess with it)
- You should be in your home directory when you do this
– The command “pwd” prints your working directory, which should read /u/horns<yournumber> if you are in your home directory
– A shortcut back to your home directory if you ever need is “cd
~”

# Virtual Environments

- A virtual environment is an isolated Python workspace for a specific project
- It contains its own Python interpreter and installed packages
- Packages installed in the venv do not affect the system Python installation
- You can make as many as you need
- If you want to share your project, you can create a dependency file (e.g., requirements.txt) so others can recreate the same environment
- On these computers you need to be in one to install new Python packages

# Making a Virtual Environment

- In your terminal type
python3 –m venv <myvenv>
- This creates a new folder named <myvenv> with its own Python executable and its own directories for installed packages
- Activation scripts are installed
- In the terminal type
source <myvenv>/bin/activate
- You now have activated the virtual environment in this terminal
- You can download packages now

# Download PySerial, Try Example

## - With your activated environment install PySerial

pip install pyserial

## - “pip” contacts the Python Package Index to find the pyserial package - It then downloads the package files and any required dependencies and installs into the currently active Python environment

# Try out an example

- On the github, download or copy/paste into a text editor the “hapkitCommands.py” file
- This file accompanies the spring_wall_damper_ISR.ino arduino sketch
- Run the arduino sketch
- In your terminal, navigate to the directory where you have placed “hapkitCommands.py” and type:
python hapkitCommands.py
- You should now be able to command the hapkit from your terminal using python

# Writing New Code

## - You can write new python scripts in any text editor and save the file with a .py extension

- Looks like these computers have vscode, idle,

## vim, etc. so just take your pick

# Resources

- Python tutorial https://docs.python.org/3/tutorial/index.html
– Feel free to use whatever tutorial you find useful
- Navigating linux directories https://docs.ycrc.yale.edu/PIL/02-filedir/
- Python packages that may be useful
– tkinter is great for building GUIs and basic games
– pygame is more geared toward games, can do 3D
- pygame.mixer can even add sound effects which can enhance haptic realism!
– matplotlib for more scientific visualization, plotting
– pyqtgraph good for live data streams
– numpy for fast, advanced math operations
– scipy for scientific computing (signal processing, filtering, optimization) – pandas for data logging – save files as CSVs and whatnot
- Some campers are also getting great results using HTML

# Go forth and create

- This was a super simple example, but you can now use the vast world of python packages to create GUIs, games, link kits together, etc.
- Feel free to use LLMs, but please try and read the code they generate to understand what is going on
– Vibe code your hearts out if you want but
– Ask the LLM why things are the way they are!
- Share with the camp!
– There’s new directory in the github called camper_scripts
– Upload your own folder with your required files and a readme to get people up to speed if they want to try it out on their own

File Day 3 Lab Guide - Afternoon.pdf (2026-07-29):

ROSS NEUMAN
Assistant Professor of Practice, The University of Texas at Austin

SUMMER 2026


## LONGHORN HAPKIT

Lab guide #3

Enhancing realism

- Once your velocity is dialed and damping feels good to you, you can use your new time-based signals to add realism to some previous environments
- We can also move on to dynamic simulations

Recall your 1 Degree of Freedom Wall


Discussion
1. In what ways does this
algorithm feel like a real wall?
2. How does it not feel like a wall?
3. How could you make it feel
more like a wall?


Stanford University | ME 327: Design and Control of Haptic Systems | © Allison M. Okamura, 2019

Stanford University; ME 327: Design and Control of Haptic Systems; © Allison M. Okamura, 2019

Damping for Virtual Walls
• a pure spring force for a wall may seem to “active”
• add a dissipative term, where b is the damping
coefficient
• only damps when going into the wall
• this can also create vibrations upon wall impact

Display impact vibrations!


Kuchenbecker, et al. 2006

– Decaying Sinusoid

Event-Based Haptics CANVAS #10, Kuchenbecker

• Add some additional event upon
object collision to give impression
of stiffer object.
– Fixed-Width Pulse

Decaying sinusoid code


- Declare these
variables

Decaying sinusoid code


- Then for your calculations

Decaying sinusoid code

- Mess around with parameter values
– Change frequency, change amplitude, etc.
- It’s pretty subtle at present but you can make it very noticeable
- Try to make the “realest” wall you can

Frictional Damping
- surfaces can feel unnaturally slippery
- friction would help, but there are different ways to implement it
- Introduce a “sticky” feel when velocity is low


Different friction Displays


- Can be difficult to render due to non-linearity

Richard & Cutkosky


Logic for coulomb friction

Dynamic Simulation of “Rigid” Bodies

- assumptions
– you have an impedance-type force-feedback display – you are using a linear stiffness model of the surface
- basic approach:
1. save the state of the moving object
2. sum the forces on the object
3. calculate the new state

Object State

- the “state” of an object is used to describe it’s current condition
- made up of variables that will change with time, such as
– position
– velocity
– Acceleration

x = 0 at equilibrium

– rarely: other parameters such as mass, shape, etc. that might be changed by dynamic interaction

Calculate the Forces on an Object

- for forces from the user’s hand pushing, this is equal and opposite to the force fed back to the user
- for forces from
other objects in
the VE, use the
same idea: force
is proportional
to penetration


Stanford University | ME 327: Design and Control of Haptic Systems | © Allison M. Okamura, 2019

The new state

- now you have a new position, velocity, and acceleration of the object
- use new position for collision detection, penetration and force calculation
- store velocity and acceleration for the next integration
- do the loop again

Pseudocode

- store last_ObjAcc, last_ObjVel
- ObjForce = Force_from_user + Force_from_other_objects
- Force_from_user = k*penetration_distance_user
- Force_from_other_objects = k*penetration_distances_objects
- can add other effects (e.g. damping) as well
- ObjAcc = ObjForce/mass (F=ma -> a = F/m)
- integrate using (for example) the trapeziodal rule:
ObjVel += 1/2(last_ObjAcc + ObjAcc)/sim_freq ObjPos += 1/2 (last_ObjVel + ObjVel)/sim_freq

Real code


Real code


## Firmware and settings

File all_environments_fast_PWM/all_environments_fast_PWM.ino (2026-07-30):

#define ENCODER_OPTIMIZE_INTERRUPTS
#include <Encoder.h>

//PWM MUST BE ON PIN 9 for this version to run (PWM is configured on Timer1 which controls pin 9 and 10 pwm)

//This code is equivalent to all_environments.ino except with fast PWM enabled
//PWM commands are now scaled to 400 instead of 255

/*
=======================
Haptic Modes:
=======================
0 - Reset
1 - Spring
2 - Wall
3 - Wall with Damping
4 - Damper
5 - Nonlinear Friction
6 - Bump
7 - Better Bump
8 - Bump and Valley
9 - Hard Surface
A - Mass Spring Damper
========================
========================
*/


// Pin Declarations
const int MotIn1 = 5;
const int MotIn2 = 4;
const int pwm = 9;

const int encA = 2;
const int encB = 3;

Encoder encoder(encB, encA);

// Encoder / Geometry
const float encoderResolution = 48.0;

const float rh = 8.5;  // handle length [cm]
const float rp = 0.5;  // motor pulley radius [cm]
const float rs = 7.5;  // sector radius [cm]

// State Variables
volatile float pos = 0;

volatile float xh = 0;
volatile float xh_prev = 0;

volatile float vh = 0;
volatile float vh_prev = 0;

float tPulley = 0;
float tS = 0;

// Timing / Filtering
const float dt = 0.001;
const float fc = 20.0;
const float r = exp(-2.0 * PI * fc * dt);

// Force Command
volatile float motorCommand = 0;

// Environment Selection
char mode = '0';


// Evironment variables that get reset with 0 mode
float x_msd = 0.5;
float v_msd = 0;
float a_msd = 0;

float xi_msd = 0.5;

float Decay_Sine_Amplitude = 0;
int Decay_In_Wall_Flag = 0;
float Decay_Sine_Time = 0;
// ===================================================
// Setup
// ===================================================
void setup() {
  //initialize motor outputs
  pinMode(MotIn1, OUTPUT);
  pinMode(MotIn2, OUTPUT);
  pinMode(pwm, OUTPUT);

  //initialize motor direction
  digitalWrite(MotIn1, HIGH);
  digitalWrite(MotIn2, LOW);



  Serial.begin(115200);

  //set up PWM on Timer1 so it's faster and we don't hear the annoying hum anymore
  //this stuff is more in the weeds, please consult the ATmega328/P datasheet for more detailed info (p. ~170)
  //set phase and frequency correct pwm at 20kHz:
  TCCR1A = (1 << COM1A1);               //non-inverting PWM on OC1A (pin 9)
  TCCR1B = (1 << WGM13) | (1 << CS10);  //waveform generation mode 8 (phase/freq correct, ICR1 top), prescaler = 1
  ICR1 = 400;                           //ICR1 defines TOP in WGM8
  OCR1A = 0;                            //initialize at 0 duty cycle
  // the results of the above code is:
  // freq_PWM = freq_CPU / (2 * prescaler * TOP)
  // freq_PWM = 16,000,000 / (2 * 1 * 400) = 20,000 or 20 kHz

  // Setup 1kHz ISR
  cli();

  TCCR2A = 0;
  TCCR2B = 0;

  TCCR2A |= (1 << WGM21);
  TCCR2B |= (1 << CS22);

  OCR2A = 249;

  TIMSK2 |= (1 << OCIE2A);

  sei();
}

// ===================================================
// Motor Driver
// ===================================================
void setMotor(int command) {

  if (command > 400) command = 400;
  if (command < -400) command = -400;

  if (command >= 0) {
    digitalWrite(MotIn1, HIGH);
    digitalWrite(MotIn2, LOW);
    OCR1A = command;
  } else {
    digitalWrite(MotIn1, LOW);
    digitalWrite(MotIn2, HIGH);
    OCR1A = -command;
  }
}

// ===================================================
// Main Loop
// ===================================================
void loop() {

  if (Serial.available()) {
    mode = Serial.read();
  }

  switch (mode) {

    // =======================
    // Reset
    // =======================
    case '0':
      {
        motorCommand = 0;

        encoder.write(0);
        pos = 0;

        x_msd = xi_msd;
        v_msd = 0;
        a_msd = 0;

        Decay_In_Wall_Flag = 0;
        Decay_Sine_Time = 0;
        Decay_Sine_Amplitude = 0;

        break;
      }

    // =======================
    // Spring
    // =======================
    case '1':
      {
        const float k = 80.0;
        motorCommand = -k * xh;
        break;
      }

    // =======================
    // Wall
    // =======================
    case '2':
      {
        const float x_wall = 2.0;
        const float k_wall = 200.0;
        if (xh > x_wall)
          motorCommand = -k_wall * (xh - x_wall);
        else
          motorCommand = 0;

        break;
      }

    // =======================
    // Wall with Damping
    // =======================
    case '3':
      {
        const float x_wall_damped = 2.0;
        const float k_wall_damped = 200.0;
        const float b_wall_damped = 5.0;

        if (xh > x_wall_damped) {
          motorCommand =
            -k_wall_damped * (xh - x_wall_damped)
            - b_wall_damped * vh;
        } else {
          motorCommand = 0;
        }

        break;
      }

    // =======================
    // Damper
    // =======================
    case '4':
      {
        const float b = 8.0;
        motorCommand = -b * vh;
        break;
      }

    // =======================
    // Nonlinear Friction
    // =======================
    case '5':
      {
        const float Fc = 80.0;
        const float vth = 0.2;
        const float k = Fc / vth;

        if (vh > vth) {
          motorCommand = -Fc;
        } else if (vh < -vth) {
          motorCommand = Fc;
        } else {
          motorCommand = -k * vh;
        }

        break;
      }

    // =======================
    // Bump
    // =======================
    case '6':
      {
        float bump_location = 2.0;
        float bump_width = 1.0;
        float bump_force = 150.0;

        if (abs(xh - bump_location) < bump_width / 2.0) {
          motorCommand = -bump_force;
        } else {
          motorCommand = 0;
        }

        break;
      }

    // =======================
    // Better Bump
    // =======================
    case '7':
      {
        float bump_location = 2.0;
        float bump_width = 1.0;
        float bump_force = 150.0;

        if ((xh > bump_location - bump_width / 2.0) && (xh < bump_location)) {

          motorCommand = -bump_force;
        } else if ((xh >= bump_location) && (xh < bump_location + bump_width / 2.0)) {

          motorCommand = bump_force;
        } else {

          motorCommand = 0;
        }

        break;
      }

    // =======================
    // Bump and Valley
    // =======================
    case '8':
      {
        float bump_location = 2.0;
        float bump_length = 3.0;
        float bump_height = 2.0;
        float bump_k = 200.0;

        float valley_location = -2.0;
        float valley_length = 3.0;
        float valley_height = 2.0;
        float valley_k = 150.0;

        if ((xh <= (bump_location + bump_length / 2.0)) && (xh >= (bump_location - bump_length / 2.0))) {

          motorCommand =
            bump_k * bump_height * cos(PI / bump_length * (xh - bump_location)) * sin(PI / bump_length * (xh - bump_location));
        } else if ((xh <= (valley_location + valley_length / 2.0)) && (xh >= (valley_location - valley_length / 2.0))) {

          motorCommand =
            -valley_k * valley_height * cos(PI / valley_length * (xh - valley_location)) * sin(PI / valley_length * (xh - valley_location));
        } else {

          motorCommand = 0;
        }

        break;
      }

    // =======================
    // Hard Surface
    // =======================
    case '9':
      {
        const float x_wall_hard = 2.0;
        const float k_wall_hard = 200.0;

        const float Decay_Sine_Amplitude_Scale = 5.0;
        const float Decay_Sine_Amplitude_Max = 30.0;

        const float Decay_Sine_Frequency = 200.0;
        const float Decay_Sine_Exponent = -20.0;

        if (xh > x_wall_hard) {

          if (Decay_In_Wall_Flag == 0) {

            Decay_Sine_Time = 0;

            Decay_Sine_Amplitude =
              Decay_Sine_Amplitude_Scale * fabs(vh);

            if (Decay_Sine_Amplitude > Decay_Sine_Amplitude_Max) {
              Decay_Sine_Amplitude =
                Decay_Sine_Amplitude_Max;
            }

            Decay_In_Wall_Flag = 1;
          }

          motorCommand =
            -exp(Decay_Sine_Exponent * Decay_Sine_Time)
            * Decay_Sine_Amplitude
            * sin(2.0 * PI * Decay_Sine_Frequency * Decay_Sine_Time);

          motorCommand +=
            -k_wall_hard * (xh - x_wall_hard);

          Decay_Sine_Time += dt;
        } else {

          Decay_In_Wall_Flag = 0;
          Decay_Sine_Time = 0;
          Decay_Sine_Amplitude = 0;
          motorCommand = 0;
        }

        break;
      }

    // =======================
    // Mass Spring Damper
    // =======================
    // *try zeroing your handle all the way to the left before running this one for better effect
    case 'A':
      {
        float m_msd = 1.0;    //mass
        float b_msd = 0.2;    //damping coefficient
        float k_msd = 50.0;   //spring stiffness
        float k_user = 100.0; //collision stiffness

        // simple integration to get velocity and position
        v_msd += a_msd * dt;
        x_msd += v_msd * dt;

        if (xh > x_msd) {
          //contact
          a_msd =
            (k_user * (xh - x_msd)
             + k_msd * (xi_msd - x_msd)
             - b_msd * v_msd)
            / m_msd;

          motorCommand =
            k_user * (x_msd - xh);
        } else {
          //no contact
          motorCommand = 0;

          a_msd =
            (k_msd * (xi_msd - x_msd)
             - b_msd * v_msd)
            / m_msd;
        }

        break;
      }
  }

  Serial.print("xh: ");
  Serial.print(xh);
  Serial.print(" ");
  Serial.print("PWM: ");
  Serial.println(motorCommand);

  delay(5);
}

// ===================================================
// 1 kHz Interrupt Service Routine
// ===================================================

ISR(TIMER2_COMPA_vect) {

  pos = encoder.read();

  tPulley =
    (pos / encoderResolution) * 2.0 * PI;

  tS =
    (tPulley * rp) / rs;

  xh =
    (rh * rp * tPulley) / rs;

  vh =
    r * vh_prev + (1.0 - r) * (xh - xh_prev) / dt;

  xh_prev = xh;
  vh_prev = vh;

  setMotor((int)motorCommand);
}

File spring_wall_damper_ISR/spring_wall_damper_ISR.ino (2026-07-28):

#define ENCODER_OPTIMIZE_INTERRUPTS
#include <Encoder.h>

// Pin Declarations
const int MotIn1 = 5;
const int MotIn2 = 4;
const int pwm = 9;

const int encA = 2;
const int encB = 3;

Encoder encoder(encB, encA);

// Encoder resolution
const float encoderResolution = 48.0;

// Mechanism dimensions [cm]
const float rh = 8.5;   // handle length
const float rp = 0.5;   // motor pulley radius
const float rs = 7.5;   // sector radius

// Variables for kinematics
float pos = 0;      // encoder position (radians)
float xh = 0;       // position of the handle [we will calculate it in cm in code below]
float xh_prev = 0;  // previous handle position

// velocity using 1st-order low-pass filter
float vh = 0;         // handle velocity
float vh_prev = 0;    // previous velocity
float dt = 0.001;  // time steps of 1ms (1kHz control loop)

// define "r" based on cutoff frequency
float fc = 20;                //cutoff frequency [Hz]
float r = exp(-2*PI*fc*dt);   //filter constant

float tPulley = 0;  //motor pulley angle (radians)
float tS = 0;       //sector angle (radians)

float motorCommand = 0;

// Selected virtual environment
char mode = '0';

void setup() {
  pinMode(MotIn1, OUTPUT);
  pinMode(MotIn2, OUTPUT);
  pinMode(pwm, OUTPUT);

  digitalWrite(MotIn1, HIGH);
  digitalWrite(MotIn2, LOW);

  // Configure control interrupt with Timer2 to make 1kHz control loop
  cli();  //disable interrupts

  TCCR2A = 0;
  TCCR2B = 0;
  
  // waveform generation mode 2 -- clear timer on compare match (CTC) mode
  TCCR2A |= (1 << WGM21);

  // Prescaler = 64
  TCCR2B |= (1 << CS22);

  OCR2A = 249;
  // freq = freq_cpu / (prescaler * (1 + OCR2A))
  // freq = 16,000,000 / (64 * (1 + 249)) = 1000 Hz or 1 kHz
  // no multiplication by factor of 2 in denominator as Timer2 is single-slope (Timer1 is dual-slope)

  // enable interrupt
  TIMSK2 |= (1 << OCIE2A);

  sei();   // enable interrupts


  Serial.begin(115200);
}

void setMotor(int command) {

  // Limit to PWM range
  if (command > 255) command = 255;
  if (command < -255) command = -255;

  if (command >= 0) {
    digitalWrite(MotIn1, HIGH);
    digitalWrite(MotIn2, LOW);
    analogWrite(pwm, command);
  } else {
    digitalWrite(MotIn1, LOW);
    digitalWrite(MotIn2, HIGH);
    analogWrite(pwm, -command);
  }
}

void loop() {

  // Read encoder
  pos = encoder.read();

  // Kinematics
  tPulley = (pos / encoderResolution) * 2.0 * PI;
  tS = (tPulley * rp) / rs;

  // Handle displacement [cm]
  xh = (rh * rp * tPulley) / rs;

  // Update mode if a serial command arrives
  if (Serial.available()) {
    mode = Serial.read();
  }

  // Compute force continuously
  switch (mode) {

    // No movement/ zeroing
    case '0':
    {
      motorCommand = 0;
      encoder.write(0);
      pos = 0;
      break;
    }

    // Virtual spring
    case '1':
    {
      const float k = 20.0;
      motorCommand = -k * xh;
      break;
    }

    // Virtual wall
    case '2':
    {
      const float x_wall = 2.0;
      const float k_wall = 200.0;

      if (xh > x_wall) {
        motorCommand = -k_wall * (xh - x_wall);
      } else {
        motorCommand = 0;
      }
      break;
    }

    // Virtual damper
    case '3':
    {
      const float b = 8;      //damping coefficient
      motorCommand = -b * vh;  //multiplied by velocity
      break;
    }

  }

Serial.println(xh);

}

//Haptic loop running at 1kHz using an interrupt service routine (ISR) for reliable calling
ISR(TIMER2_COMPA_vect) {

  // read encoder
  pos = encoder.read();

  tPulley = (pos / encoderResolution) * 2 * PI; //angular position of motor pulley in radians

  tS = (tPulley * rp) / rs; //angular position of sector pulley in radians

  //determine handle position in cm
  xh = (rh * rp * tPulley) / rs;
  
  // handle velocity (cm/s) using a 1st-order low pass filter with constant r defined in setup()
  vh = r * vh_prev + (1 - r) * (xh - xh_prev) / dt;

  // update "previous" terms for next loop
  xh_prev = xh;
  vh_prev = vh;

  // command motor based on duty cycle (-255 to 255)
  setMotor(int(motorCommand));
}
